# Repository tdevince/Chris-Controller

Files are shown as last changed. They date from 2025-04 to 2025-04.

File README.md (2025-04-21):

# Chris-Controller

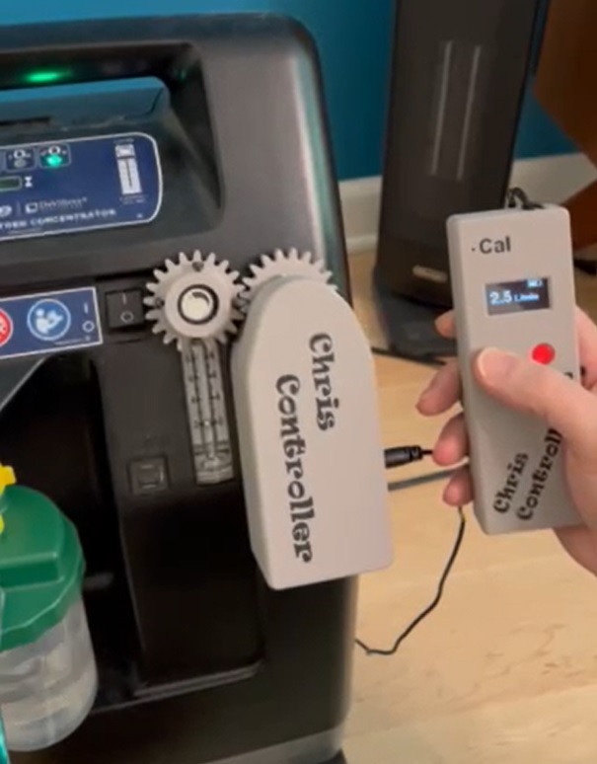
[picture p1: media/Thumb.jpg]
Watch the video
[](https://private-user-images.githubusercontent.com/97317875/435509045-00b4797d-aa02-43c4-9b9c-edfc26d2068e.mp4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)

This project is dedicated to my sister who is forced to live with a stationary oxygen concentrator 
in her house. The unit is extremely loud and not placed in a part of the house she wants to sleep 
or be in.  However, to change the oxygen flowrate, it is necessary for someone to do it at the machine.
For someone who is not mobile, this is a dificult task.  Further complicated by the fact that
in order to get up, she must first increase her oxygen flowrate.  Not possible without a caretaker
to go to the unit and manually change it.  

While some oxygen concentrators are available with remote control flow systems, they are not
FDA approved (as of this writing), as such medical supply companies do not provide these
units.

Her options are to increase the flow at the concentrator and use a second flowmeter at her location
that moves with her.  This creates a few problems, first the backpressure for the remote flowmeter
does not allow humidification at the concentrator to work properly.  Thus she is left with dry oxygen
which results in discomfort and nose bleeds.  Second, the backpressure can cause the concetrator
to alarm repeately.  Finally, this requires more hoses at her end of the system, which tangle and 
get caught when she tries to go to her walker or wheel chair.

The following paper by Duke University (https://pmc.ncbi.nlm.nih.gov/articles/PMC10122499/) provides
the basis for which this project is undertaken.  The project recommends that the controller at the 
stationary concentrator communicate via Bluetooth to a iPhone.  This requires an app on the iPhone to
controll the unit at the concentrator.  Since I'm not that well versed in creating applications for
the Apple Store, I instead created a remote control unit (based upon the ESP32-S2 chip, using the
ESP-NOW protocol).  This system uses the 2.4GHz WiFi frequency, but does not require connection
to a local WiFi network.

Since the paper that describes the hardware is a non-commercial license (CC BY-NC 3.0), the hardware
portion of this project is non-commercial. However, the software code developed for this project
is licensed under GNU General Pulbic License

## Repository Files:

* Files necessary for 3D printing are in the folder "3D Print Files".
* The Fusion360 files used to create these files are in the folder titled "Fusion360"
* An instruction manual that describes the operation and use of the system is included as a *.pdf file in the "Instruciton Manual" folder.  
* The circuit was designed using KiCad 9.0.  The schematic as well as the PCB files are in the folder "KiCad 9.0 fiies".  This folder also has the gerber files, position files and BOM files necessary for ordering the PCB's from JLCPCB.com.
* Two other repositories are used for the code used to program the controller and the remote.  The links to these repositories are in the folders "Controller" and "Remote".

## Building the Controller:

To build the Chris Controller, you will need to make the controller as well as the remote control.  The Controller consists of 3 3D printed gears, a mounting plate for the stepper motor and potentiometer and a base and cover.  The Fusion 360 files used to create the files for printing are included.  The parts were output to *stl files that were imported into PrusaSlicer.  The 3D input and output files are included in the Controller Directory.  PETG was used to print all parts. The potentiometer mounting plate requires supports on the dished part that holds the potentiometer.  The Cover has supports on the portion of the opening that accepts the 12V plug.  No other parts required supports for printing.
The stepper motor used is the 28BYJ-48 stepper motor.  This motor is found in 12V and 5V versions.  This project used the 12V version.  The potentiometer uses is the Bourns 3590-2-103L 10k ohm multiturn potentiometer.  The output jack supplied with the stepper motor is the JST 5 pin XH series connector.  The mating male connector is used on the PCB.  The potentiometer is connected to the PCB using the 2 pin JST connectors (XH series as well).  
The controller for the stepper is the ULN2003A Darlington array DIP.  Rather than use an SMT part, the DIP package was used since this is a common failure point of stepper motor systems.  Thus, using a 16pin socket on the PCB, the ULN2003A is easily replaceable.
The PCB uses an ESP32-S2-Solo-2 module for a microcontroller.  This module has the WiFi antenna included.  The code for the controller and remote uses the ESP-NOW protocol for communication.  This eliminates the need for a WiFi connection but provides superior range over a Bluetooth connection.  

The schematic and gerber files to order the PCB are provided in the KiCad directory.  The BOM used to order the PCB’s do not include the ESP32 module or any through hole parts (sockets, etc.) since these are easily added.  The ESP32 module is relatively inexpensive, but when supplied as a separate module, and not part of development kit, it must first be programmed prior to soldering to the PCB.  There is no way to update the firmware of the ESP32 once installed, other than Over-The -Air updates.  Therefore, the first loading of the firmware requires a wired connection to a PC.  Using a development board with flexipins allows for easy programming of the ESP32 module before installing.  If such a board is not available (I made my own for such purposes), the schematic and PCB can be redesigned to use a ESP32-S2-DevkitC-1.  This will increase the footprint of the PCB, but can be made functional.
The power supply used is a standard 12VDC adapter.  The stepper and ULN2003A take 12V inputs, the ESP32 is supplied with 3.3V from a buck switching regulator.  A switching regulator was chosen for its efficiency.  If a linear regulator is used, accommodation for heat dissipation must be considered since dropping from 12V to 3.3V will involve significant heat on linear regulators.

## Building the Remote:

The remote 3d files print a total of 7 items.  These are:
	Remote Cover
	Remote Base
	Up Button
	Down Button
	Battery Box
	Battery Box Cover

The Remote Cover and the Battery Box print as two items each if you want to print text(on the cover) and battery icons (on the battery box).  The text and icons are two different parts in the Fusion360 files.

To print different colors on the same layer in Prusaslicer, first go to “General” settings and change the number of extruders to 2.  Then on the Custom Code, enter “M600” for tool change.  This will cause the printer to pause and prompt to load a new color.  This method works well when only one or two layers need a different color inserted (such as text or battery icons).  When using this method, it is best if the text/icon part is part #2.  This way the rest of the layer is printed first, and success rate is higher in getting the text to look good without lifting or other print errors.

The *.gcode files are set up to print the multicolor as described above.  The cover is designed to have a 1mm thick acrylic sheet as a display window to protect the OLED screen.  The window cover should be cut and fit to the space in the cover before gluing.  Use a 5 minute epoxy rather than a CynoAcrylic (CA, Superglue, etc.) type of glue.  The CA glues will tend to fog the acrylic sheet.

The battery box uses a total of 8 keystone style 5209 terminal clips.  The clips are inserted into the box, and the tabs then bent outward 90 degrees.  The tabs then may be soldered to provide the 4 cells in series (i.e. positive to negative with the first and last tabs being the +6V and -0V tabs).

The positive tab is then routed to the slide switch (the cover is designed to use the CW Industries model G-107-SI-0005 slide switch.  The output of the slide switch, with the negative terminal of the battery box are then connected to the PCB using a JST XH series two pin connector.

Once the battery box is soldered, it may then be glued into the cover.  There are indexing tabs designed into the battery cover for the battery box.  

The two buttons (Up and Down) are also printed in PETG, I used red to offset it from the urban grey I used for the remainder of the remote.  These buttons merely fit inside the cover and are held into position by the PCB and push buttons.  The push buttons used are similar to https://www.amazon.com/Tactile-Switch-Momentary-Arduino-6x6x5mm/dp/B06XRH6GNX

Only two buttons are exposed by to the push buttons that are printed (the up and down buttons).  The calibration button is accessible using a paper clip through the small hole in the upper left of the remote cover.  The fourth button of the PCB is for OTA updates and is not accessible with the cover in place.

The remote uses a 1.3” OLED monochrome I2C display.  Note the order of the 4 contacts on the PCB to ensure that the one you are using will work, if not a redesign of the PCB may be necessary so that SDL, SCL, VCC and GND align.  The OLED uses the SH1106 chip, thus the library for the remote codes is built around this display.

Similar to the controller, the remote uses an ESP32-S2-Solo-2 bare module (https://www.digikey.com/en/products/detail/espressif-systems/ESP32-S2-SOLO-2-N4/16591892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) .  

The module will need to be programmed before soldering to the PCB, so that OTA updates are possible.  The advantage of using the bare module rather than development board is that it drastically reduces the footprint on the PCB (thus a smaller remote) as well as reducing the vampire load when the module is put to sleep.  Most development boards use a linear voltage regulator, which will consume much more battery power than the switching regulator used in this design.

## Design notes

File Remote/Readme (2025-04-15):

The code for the Chris Controller Remote is in the following repository:

https://github.com/tdevince/ESP32_Chris_Remote.git

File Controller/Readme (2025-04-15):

The code for the controller is located in the
following repository

https://github.com/tdevince/ESP32_Chris_Controller.git

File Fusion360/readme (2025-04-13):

This folder includes the Fusion360 files that wwere used to create the 3D printed
files for the controller and remote enclosure as well as gears.

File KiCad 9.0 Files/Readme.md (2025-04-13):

This folder contains the KiCad files for the schematic and PCB layout
in the formate required by JLCPCB.com.  Also included is the BOM and
position file that JLCPCB requires for assembly.  The BOM and postion
file do not include information the push buttons, connectors or
ESP32-S2-Solo-2 module since these are manually soldered after
receipt of the manufactured PCB's.

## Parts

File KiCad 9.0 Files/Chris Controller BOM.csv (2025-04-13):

Comment | Designator | Footprint | LCSC Part Number
4.7uF | C1 | Capacitor_SMD:C_1206_3216Metric | C29823
100nF | C2 | Capacitor_SMD:C_0402_1005Metric | C307331
1uF | C3 | Capacitor_SMD:C_1206_3216Metric | C1848
22uF | C4,C5,C6 | Capacitor_SMD:C_0805_2012Metric | C45783
1uF/25V(10%) | C7 | Capacitor_SMD:C_0402_1005Metric | C52923
10uF/25V(20%) | C8 | Capacitor_SMD:C_0603_1608Metric | C96446
0.1uF/50V(20%) | C9 | Capacitor_SMD:C_0603_1608Metric | C14663
24k | R1 | Resistor_SMD:R_0603_1608Metric | C23352
10k | R2 | Resistor_SMD:R_0603_1608Metric | C25804
10K | R3 | Resistor_SMD:R_0402_1005Metric | C25744
22k | R4 | Resistor_SMD:R_0603_1608Metric | C31850
TPSM33625 | U1 | Library:QFN-FCMOD | C7073593

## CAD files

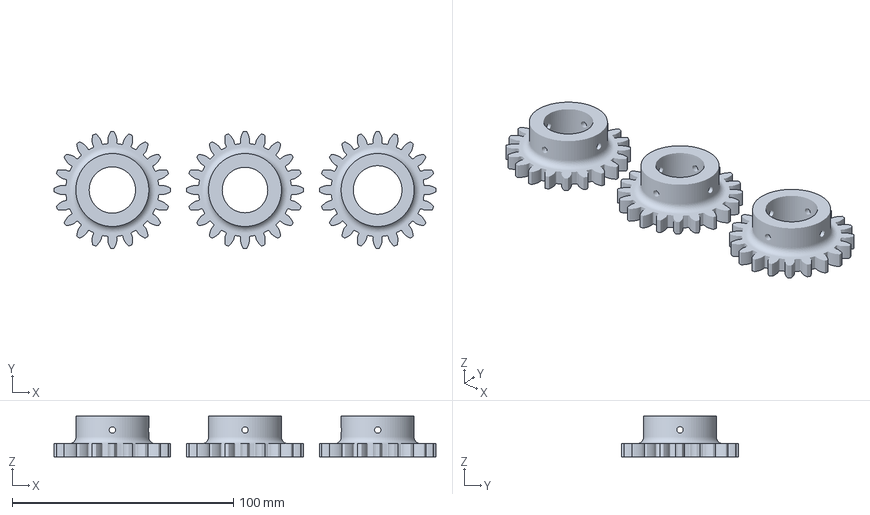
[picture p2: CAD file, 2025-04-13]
3D Print Files/Controller/Knob Gear Set.3mf
172.8 x 52.8 x 18.5 mm

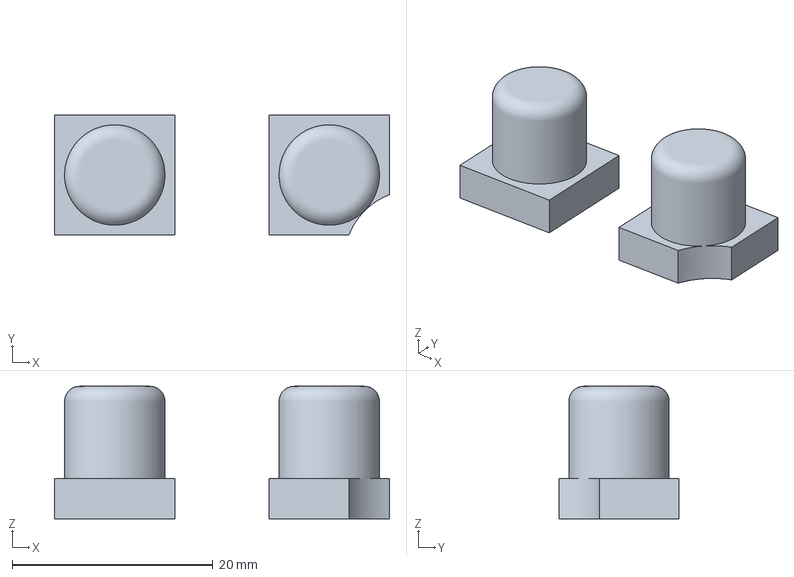
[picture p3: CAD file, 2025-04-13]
3D Print Files/Remote/Buttons.3mf
33.4 x 12.0 x 13.2 mm

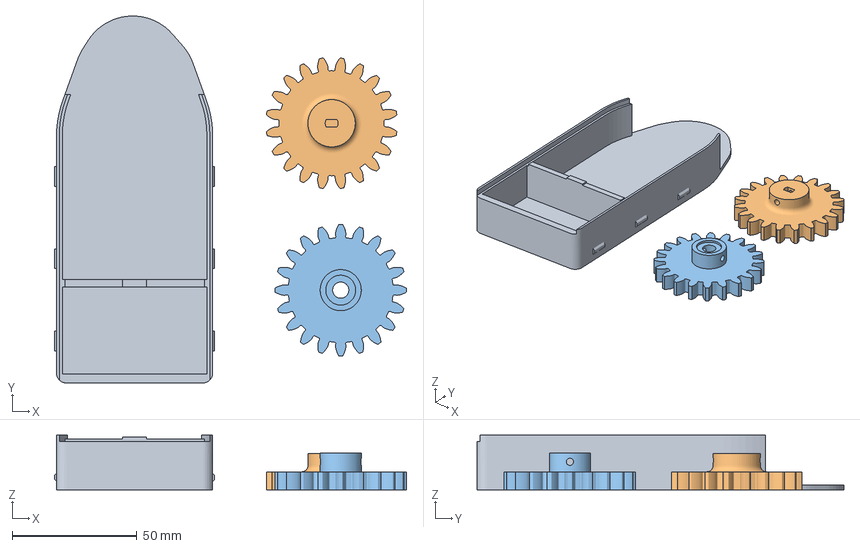
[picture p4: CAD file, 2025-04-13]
3D Print Files/Controller/Base and gears.3mf
141.3 x 147.3 x 22.0 mm
Base.stl
Drive Spur Gear (20 teeth).stl
Pot Spur Gear (20 teeth).stl

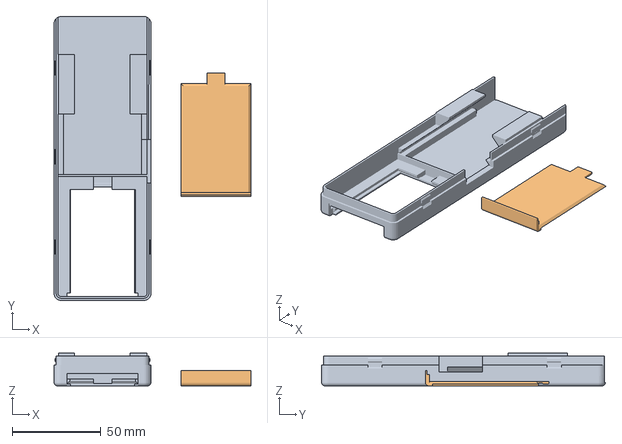
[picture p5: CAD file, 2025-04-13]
3D Print Files/Remote/Base and Cover.3mf
111.2 x 160.4 x 18.5 mm
Base.stl
Batt Cover.stl

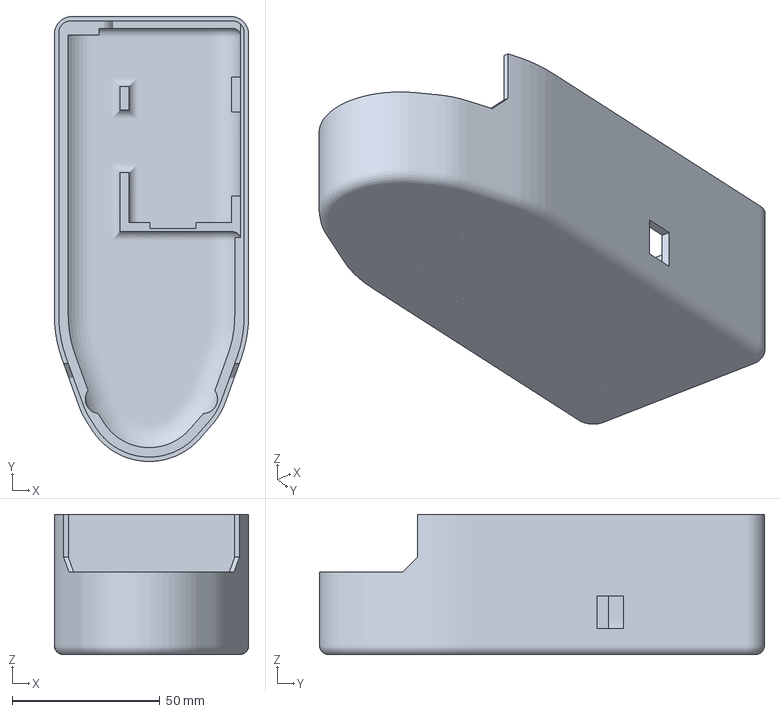
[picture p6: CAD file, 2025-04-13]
3D Print Files/Controller/Cover.3mf
65.8 x 150.7 x 47.5 mm

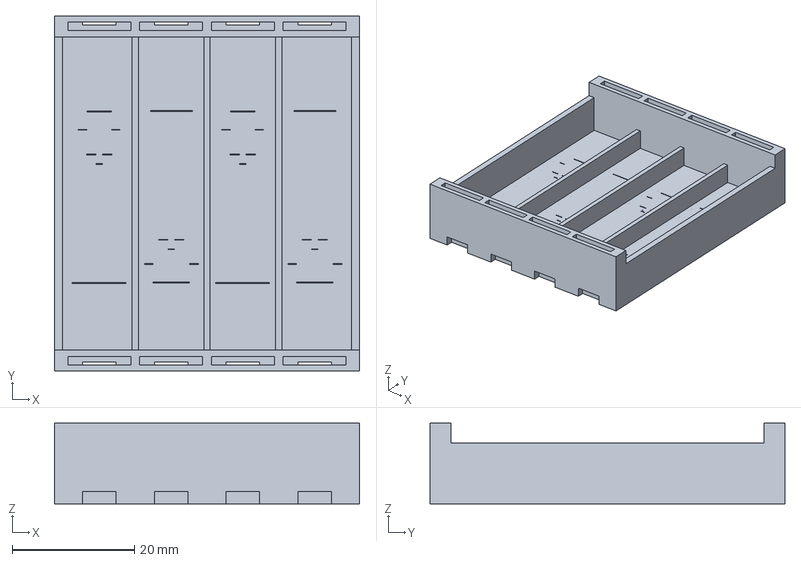
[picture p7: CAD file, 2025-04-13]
3D Print Files/Remote/Batt Holder.3mf
50.0 x 58.2 x 13.2 mm

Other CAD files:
Fusion360/Remote v21.f3d

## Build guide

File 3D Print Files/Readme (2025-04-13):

The files here were printed on a Prusa3d MK4S printer.
PETG was used for all parts, Urban Greay prusament was 
used for the enclosures, black for text and Red for 
the buttons.  
Prusaslicer was used to create the binary gcode files.

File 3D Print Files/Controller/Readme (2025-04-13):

The Fusion360 model was used to create the *.stl
files that were then imported into PrusaSlicer

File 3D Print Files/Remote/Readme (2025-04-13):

The fusion360 model was used to create *.stl files
that were used to make the .3mf files for Prusaslicer

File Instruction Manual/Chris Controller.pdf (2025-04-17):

# Chris Controller

# Static Oxygen Concentrator Remote Control System

### Table of Contents

Safety Information:
The following information is important for the safe operation of the Chris Controller system. Read through the entire manual and familiarize yourself with the system before using the system. Failure to do so may result in injury or death. Pretty dramatic, huh! Now you have to ask yourself if you really want to use something that could result in injury or death.

Rotating Machinery: This system has exposed rotating gears. Do not wear dangling or loose fitting clothing or jewelry that may get caught in the rotating gears. The Controller uses the powerful 28BYJ-48 motor in the 12V version. While it may not be enough to harm a finger, it can do serious damage to the stoutest of commercial plastic drinking straws.

Choking Hazard: There is nothing edible in this system. Every effort was made so that it doesn’t look like food. If you try to eat it, you will probably choke on it. If you’re that hungry, just get a candy bar instead.

Not a Toy: Apparently some people think it’s a good idea to give children plastic bags to play with. That is why so many manufacturers say not to play with plastic bags. To prevent you from giving children plastic bags as toys, this product is supplied without any plastic bags. Give your children a proper toy instead.

Prop. 65 Warning: Like everything else, this can cause cancer in the state of California. So do the safe thing and keep you and your loved ones out of the state of California!

Psychological Hazard: Unfortunately oxygen concentrator flow rates are typically metric (L/min). While no one knows what an “L/min” is (everyone knows what a “cubic foot per hour” is, though) this system uses metric so that it remains consistent with the oxygen concentrator system of units. For that reason, all parts of the design of this system is in metric units. For example, the set screws used are metric and use metric hex wrenches (2.5mm). While the metric system can cause psychological harm, it was determined the mixing of units would be more damaging. Thus only metric is used in the Chris Controller system.

Introduction
Stationary oxygen concentrators are typically loud and cannot be placed in rooms where one is trying to sleep or reside. Long lengths of tubing are used to connect the user to the concentrator, so the user is not in the same room with the concentrator. This presents a problem when the user needs to change the oxygen flowrate. For example, if the resting oxygen flow rate is lower than the flow need to get up and walk, then the user must increase the oxygen flow before getting up. But if the concentrator is not in the same room, another person must be available to change the flowrate.

The technical paper from Duke University titled “Design and Development of a Novel System for Remote Control of Stationary Oxygen Concentrator Flow Rate” by authors Nikhil Gadiraju, Nikhil Peterson, Jessica Shah, Annabelle Chu, Michael A Larbie II, Amy Bu, Ann Saterbak was the basis for this project (See Attachment 1).

The Chris Controller system was designed to work on the DeVilbiss Drive 10 Liter Oxygen Concentrator. This concentrator uses a manual flow meter to adjust the delivered Oxygen flow. This is similar to many concentrator designs, as such; the Chris Controller is designed to be easily adaptable to other concentrator designs.

The Controller works by grabbing the knob that adjusts the oxygen flow and turning the knob by use of a stepper motor. The Controller system is delivered with a set of three gears to grab the knob. Each of these gears is labeled 1 through 3; choose the one that best fits your knob. Gear 1 has a straight opening and provides the greatest clearance for the knob. Gears 2 and 3 have a slight taper to the opening that fits the knob, with Gear 2 being a little tighter than Gear 3.

The remote control has a set of Up/Down buttons. When Up is pressed the gear on the knob will rotate counterclockwise. On the DeVilbiss concentrator, this increases flow. If your concentrator design is opposite, then the Up/Down buttons will work opposite (Up will decrease flow, Down will increase flow).

The intent of the system is that no modifications to the concentrator are necessary. Since many people do not own the concentrator, but are instead supplied via a medical supply company, modification of the concentrator was not an option. The knob gear grabs the flow knob with a set of 4 set screws. The Controller itself is attached to the concentrator with the use of double sided tape (e.g., 3M double sided tape). No drilling or screwing into the concentrator is required for the Controller system to function.

The system includes:
- Chris Controller
- Chris Controller Remote
- Set of 3 knob gears (only one required for operation)
- AC Adapter (12VDC Output)
- Four AAA alkaline batteries

The Controller is powered by the AC adapter. The Remote uses four AAA batteries. The life of the batteries is dependent upon usage of the system.

The brains of the system are the Espressif ESP32-S2-Solo-2 microcontroller modules. These modules use an 802.11 Wi-Fi standard for communication. But instead of requiring a connection to a Wi-Fi network, the Remote and Controller communicate using Espressif’s ESP-NOW wireless protocol. This provides quicker response time than using a Wi-Fi network, while providing the superior range of Wi-Fi over Bluetooth. The Remote and Controller communicate on the 2.4GHz frequency (same as Wi-Fi networks). They use a “peer to peer” network based upon the MAC address of each ESP32 module. This information has been coded into the firmware; no pairing of devices is required by the user.

Documentation for this project, including source code and 3D models can be found at:

https://github.com/tdevince/Chris-Controller

Chris Controller:
The Controller consists of a stepper motor, a multi-turn potentiometer, a set of gears (flow meter knob gear, drive gear and pot gear). The stepper motor is able to precisely move the flow meter knob (via the gearing) in either the up or down direction (counterclockwise or clockwise). The stepper motor does not have a stop and can continue to travel in one direction infinitely.
The stepper motor is not capable of knowing where in the flow range it currently resides. It only knows turn clockwise or counterclockwise by so many steps. The stepper motor used is the 28BYJ-48 motor. This motor is most commonly available in the 5V version; this Controller uses the 12V version. The motor itself has 32 steps per revolution, but is internally geared so that it takes a total of 2048 steps to complete one rotation of the output shaft.

The potentiometer is the memory of the system. A potentiometer is a variable resistor. By turning the potentiometer we can increase or decrease resistance. The potentiometer used in the Chris Controller is a 10 turn 10kOhm resistor (Bourns model 3590S-2-103L). This means at one end of travel the resistance is 0 ohms. At the other end of travel (10 turns later), the resistance is 10,000 ohms. One complete turn of the potentiometer is equal to 1000 Ohms. By including the potentiometer in the gear train, we turn the potentiometer the same time and the same amount as we turn the flow knob when the stepper motor is engaged. All gears have the same number of teeth, so every gear turns in synchronization with each other.

After calibrating the system, the resistance of the potentiometer is directly proportional to flow rate. If power is lost, the potentiometer will retain the flow setting of the concentrator.

The system will not allow the stepper motor to hit the hard stops of the potentiometer. To help keep the full range of the full knob within the operating range of the potentiometer, it is recommended that the lowest flow rate (2.0L/min) be set with the potentiometer approximately 1.5-2 turns up from the low range stop.

Caution: Do not manually turn the flow knob, or gears while the drive gear is on the stepper motor. This may damage the internal gearing of the stepper motor.

To set the starting location of the potentiometer, remove the driver gear from the stepper motor. The gears or a snug fit on both the potentiometer and stepper motor. The gears are held to the shaft of these components with a pair of set screws. The set screws use a 2.5mm hex wrench (Allen wrench). With the drive gear removed, rotate the potentiometer gear all the way clockwise (as observed from the top of the Controller) until the stop is hit. Then rotate the gear 1.5-2.0 turns clockwise. Now reinstall the drive gear. When placing Controller on the concentrator, set the flow rate to the lowest setting (2.0 L/min). This will prevent the lowest setting of the Controller from hitting the hard stop of the potentiometer. This will provide approximately 8.5 turns of operation of the system. The concentrator flow meter will typically go from 2.0 L/min to 10.0 L/min in less than 5 turns.

The Controller is powered from the provided 12V AC adapter. This AC adapter provides an output of 12VDC with a maximum output current of 1.0Amps. This is well below the current draw of the Controller. Do not power the Controller with more than 12VDC since the stepper motor is only rated for a maximum of 12VDC.

The Controller has two modes of operation:
- Normal Mode
- Over-The-Air (OTA) mode

Operations to control the flow rate of the concentrator using the stepper motor occurs under the Normal Mode. Firmware updates to the Controller are only possible in the OTA mode. Firmware updates require a connection to a Wi-Fi network. The Printed Circuit Board (PCB) of the Controller has a button that will toggle the mode of the Controller from Normal Mode to
OTA Mode. This button is only accessible by removing the top cover of the Controller to expose the PCB.

By pressing the OTA button on the PCB, the Controller will reboot in the firmware update mode. The Controller will store the SSID and Password to connect to the local network. If the Controller has not connected to this network previously, it will present a Wi-Fi Manager Webpage that may be used to store the network SSID and Password.

While connected to a network, firmware updates may be carried out from a PC connected to the same network. Once the update is completed, pressing the OTA button on the PCB again will return the Controller to Normal Mode.

See the section on firmware updates for details.

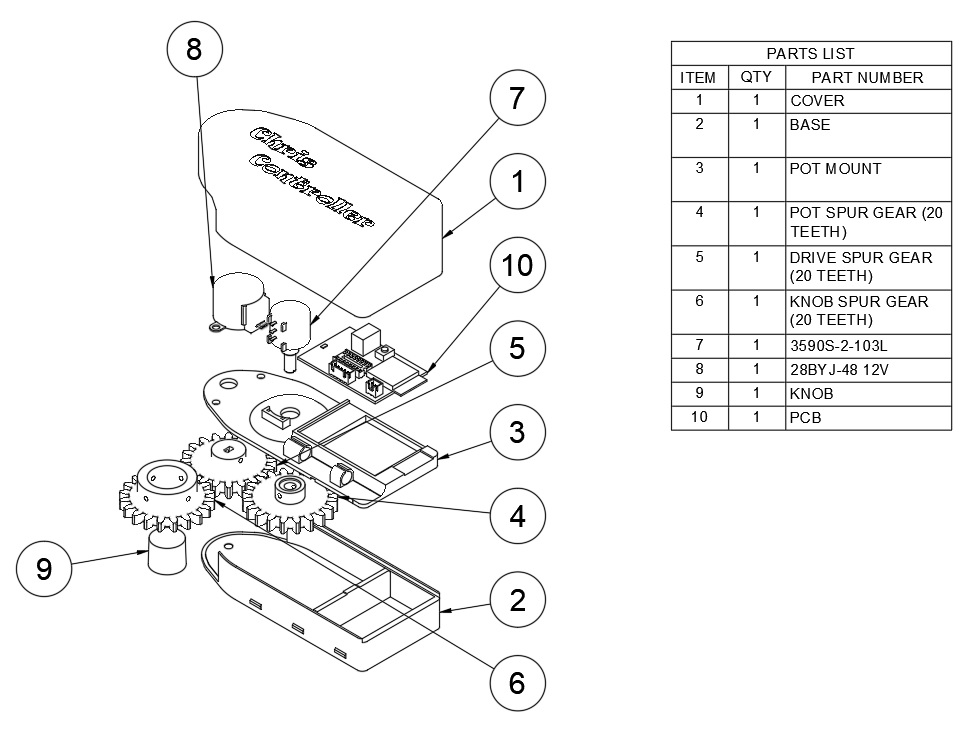
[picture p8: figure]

Page 7 of 18

Figure 1: Controller Exploded Diagram

Page 8 of 18

Remote:
The remote control is the user interface for the Chris Controller system. The Remote has two buttons, Up and Down, that allow the user to command the Controller to rotate the flow knob counterclockwise and clockwise, respectively. For concentrators where counterclockwise increases flow, the Up and Down button will increase and decrease flow, respectively.

The Remote also features a 128x64 OLED display screen. This screen will show the current oxygen flow rate for which the Controller is set. The upper right part of the display also provides an icon reflecting the remaining capacity of the 4 AAA alkaline batteries.

The upper left of the Remote has access to the Calibration feature of the Remote by inserting a paper clip (or similar object) into the hole marked “Cal”. This will press the “Cal” button on the PCB. Once the “Cal” button is pressed, instructions on how to calibrate the system is provided.

While the potentiometer of the Controller stores the current position of the concentrator flow knob, the Remote is the device that correlates the potentiometer resistance to an actual flow rate. The calibration information is stored in non-volatile memory; therefore the information is retained after the Remote has been powered down.

A slide switch on the side of the Remote turns the power on/off from the batteries to the PCB. This slide switch physically interrupts the battery to PCB connection. While powered up, to conserve batteries, the Remote display and Remote ESP32 module will go to sleep after 15 seconds of inactivity (while in the normal mode of operation). To wake the Remote, a single press of either the Up or Down button will wake the Remote. If the system is not going to be used for an extended period of time, the slide switch is the preferred method to turn the Remote off since this will conserver battery life.

The Remote during normal operation consumes approximately 60-70mA of current. When in sleep mode, this value drops to approximately 0.14mA. A typical AAA battery provides approximately 1000mA-hr of capacity. If the Remote were to be left in sleep mode, the batteries should last approximately 300 days. This value will vary by the frequency of use and the quality of batteries used. The slide switch eliminates all “vampire” loads, so that 0.0 mA are used from the batteries while powered off.

Similar to the Controller, the Remote has an OTA button on the PCB. This button is only accessible when the PCB is exposed.

The top of the Remote has a post and hole that is designed to have a lanyard attached. This feature will help avoid the dreaded “Where did I put that @*%&@#?ing Remote”crisis.

The Remote has 3 modes of operation:
- Normal Mode
- Calibration Mode
- OTA mode

Normal Mode:
Normal Mode is used for controlling the oxygen flow via the Controller. By holding the Up or Down button, the display will increase the flow demand in 0.5 L/min increments. 2.0L/min being the lowest and 10.0 L/min being the maximum flow settings possible. Once the desired flow rate is displayed on the Remote, release the buttons. When the buttons have been released for 1 second, the Remote will send the new flow demand to the Controller. The Remote will display the message “waiting…” while the Controller adjusts the flow rate. When the Controller reaches the desired flow rate, it will respond to the Remote with the current potentiometer setting. The Remote will convert this value and display it as the new oxygen flow rate.

After 15 seconds of inactivity, the Remote will go to sleep. Pressing either the Up or Down buttons will wake the Remote. Upon waking the Remote will inquire from the Controller its current position. When the Controller responds with the current potentiometer setting, the Remote will convert this value and display the corresponding oxygen flow rate.

Calibration Mode:
The Remote must be calibrated to be able to convert potentiometer values to an oxygen flow rate. Calibration is only required when initially setting up the Chris Controller. Once it has been set up, the calibration data is retained in non-volatile memory. The only time a Calibration would be required is if the flow knob is moved independent of the Controller (i.e. the flow knob on the concentrator manually moved with the Controller not installed). If the Controller is ever removed and reset on the concentrator, the calibration procedure should be repeated.

Caution: Do not manually turn the flow knob, or gears while the drive gear is on the stepper motor. This may damage the internal gearing of the stepper motor.

OTA Mode:
The OTA mode allows firmware updates of the ESP32 module of the Remote. While in Normal or Calibration Mode, the Remote is using the ESP-NOW protocol to communicate with the Controller. To enable firmware updates, the Remote must disconnect from the Controller and connect to the local Wi-Fi network.

Pressing the OTA button on the PCB will toggle the OTA Mode, and reboot the ESP32 module. Upon booting up, the ESP32 module will log on to the local Wi-Fi network using its stored SSID and Password for the Wi-Fi network. If the Remote has not connected to the Wi-Fi network previously, it will deploy its Wi-Fi Manager Webpage. This Webpage may then be used to log onto the network. Once logged on to the Wi-Fi network, the firmware on the ESP32 module may be performed with a PC connected to the same Wi-Fi network.

When logged onto the local network in OTA mode, the Remote display screen will show that the Remote is in OTA update mode and will also display its IP address. While in OTA mode, the Remote will not go to sleep.

After updating the firmware, another press of the OTA button will reboot the Remote in the Normal Mode. See the section on firmware updates for details

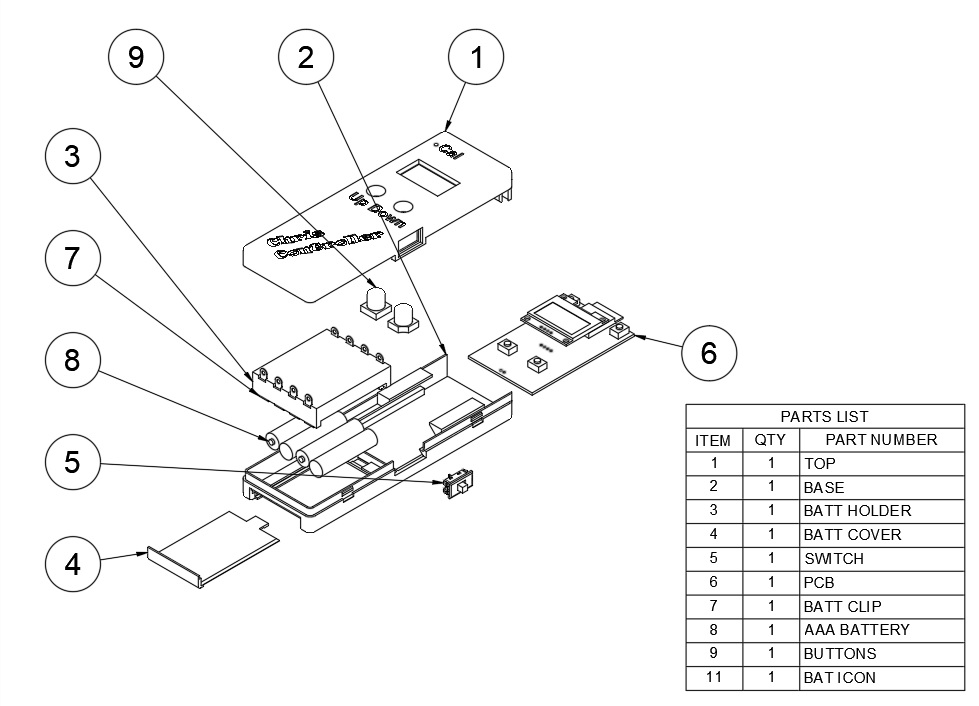
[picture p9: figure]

Page 11 of 18

Figure 2: Remote Exploded Diagram

Page 12 of 18

Installation and Setup:
The Chris Controller only requires 8 simple steps for installation. The required items for this installation that were not provided with the system are:
- 2.5mm hex wrench (Allen wrench)
- Double sided tape
Step 1:
Determine where on the concentrator the Controller should be located. On the DeVilbiss Drive 10 Liter Oxygen Concentrator, the Controller is designed to be affixed to the right of the flowmeter and flow knob. The Controller should not be installed such that the flowmeter is blocked. The drive and flow knob gears are designed to have a lateral separation of 48mm (1.9”). So the Controller should be placed such that the drive gear is offset this distance from the flowmeter.
Step 2:
Choose the appropriate flow knob gear to use. The system is supplied with three gears, each labeled 1, 2 and 3. Gear 1 has a straight wall opening to accommodate the knob, and will provide the greatest clearance. Gears 2 and 3 have tapered openings to accommodate the knob, with Gear 2 having tighter tolerances than Gear 3. The knob to choose will be the one that fits loosely around the knob but minimizes the clearance between the knob and gear.

Attach the knob by gradually tightening the 4 set screws. These screws should be used to align the gear so the knob is as close to the center of the opening as possible. By maintaining concentricity between the knob and gear, binding of gears can be minimized. Do not overtighten the set screws. It is only necessary to snug the screws so they adequately grab the knob and center the gear.

Step 3:
Dry fit the location of the Controller so that the drive gear meshes with the knob gear installed in
Step 2 above. The mesh should be slightly loose to prevent gear binding, but not so loose as to have significant backlash in the gearing. It may be necessary to reposition the knob gear up or down to ensure the drive gear and knob gear are at approximately the same height. Bear in mind when dry fitting that using a foam style double sided tape will slightly elevate the drive gear.
Step 4:
The Controller was delivered with the potentiometer set to 1.5 to 2.0 turns from the bottom stop. Therefore set the flow knob on the concentrator close to 2.0L/min to provide adequate margin when calibrating.
Step 5:
Place double sided tape on the bottom of the base of the Controller, and stick it to the concentrator such that the knob gear and drive gear mesh as described in Step 3.

Step 6:
Plug in the AC adapter and then plug it into the Controller to power the Controller.
Step 7:
Install 4 AAA batteries in the Remote, and then switch the power on the Remote. It will provide a Controller reading, this value is not accurate until the Remote has been calibrated.
Step 8:
Calibrate the Remote (See Calibration Section).

After completion of the calibration step, the Chris Controller system is ready for operation.

An optional lanyard may be attached to the post in the top of the Remote.

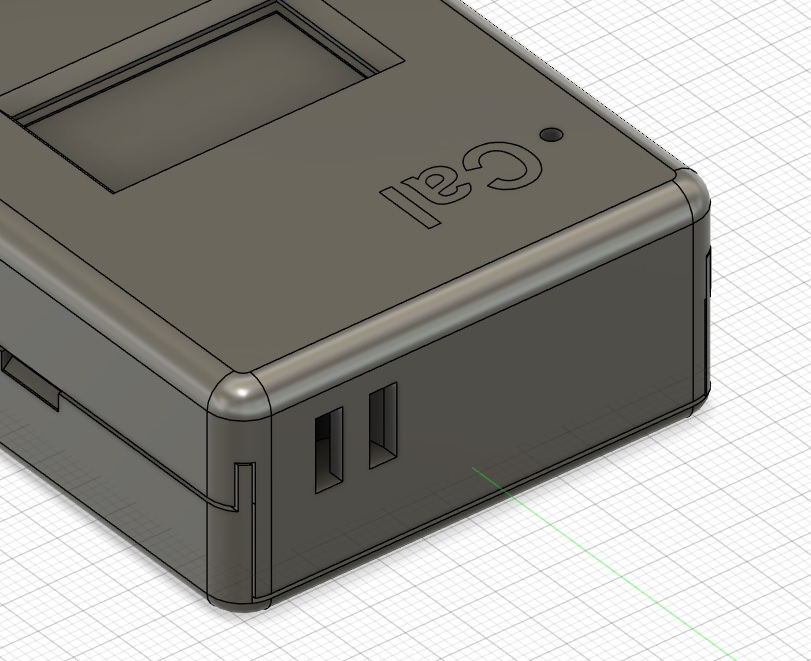
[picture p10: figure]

Figure 3: Remote Lanyard Post and Hole

Calibration:
Calibration of the system should be done anytime the knob and potentiometer gear are out of synch with each other. This will, at a minimum, be at the first installation of the system. Any other time when the knob is manually moved independent of the gear train, a calibration should be performed.

Caution: Do not manually turn the flow knob, or gears while the drive gear is on the stepper motor. This may damage the internal gearing of the stepper motor.

Calibration should be performed at the oxygen concentrator to allow visual readings of the flow rate during the process. The calibration process involves using the Remote to command the stepper motor to increase or decrease flow by pressing the Up or Down buttons. The Remote will identify the target flow rate for each step. When the target flowrate is displayed by the Remote, use the Up/Down buttons until the flowrate displayed on the oxygen concentrator matches the target value given by the Remote. When the target flowrate is achieved, pressing the Up and Down buttons simultaneously will enter this value into the Remote.

The stepper motor uses 2048 steps per revolution. Using the Remote Up or Down buttons will cause the stepper to in increments of 128 steps. This provides a resolution of 16 steps per revolution, or 22.5o
. This should provide adequate resolution for level of accuracy of the concentrator flowmeter.

The Remote will ask to repeat this process for a total of 9 data points from 2.0 to 10.0 L/min in 1.0L/min increments. After the last data point has been entered, the calibration data are saved to memory and the Remote will return to the Normal Mode.

To Calibrate the system, perform the following steps (note, the Remote will not go to sleep during calibration):

Step 1:
Ensure the Controller is powered up, turn on the Remote and wait for the display to show the current Controller position.
Step 2:
If the Remote is asleep, first wake the remote by pressing either the UP or Down button. Using a paper clip, or other similar object, insert it into the “Cal” hole located on the Remote. Press the button on the PCB with the paper clip. The Remote will now enter calibration mode and display a screen of instructions:

Cal. Mode: Use Up or
Dwn to turn controller
To desired flow. Press
Up & Down to ‘Enter’

Press the Up and Down button to progress to the next page.

Step 3:
After pressing the Up and Down buttons in Step 2, the user will be presented with the first target flow rate. Using the Up/Down buttons have the Controller increase/decrease flow on the concentrator until the flowmeter on the concentrator matches the target value displayed on the Remote. When the target value is achieved, simultaneously press the Up and Down buttons to enter the value. The Remote will then prompt the user for the next data point.
Step 4:
Repeat Step 3 until all data points from 2.0 through 10.0 L/min have been entered. The Remote only uses cardinal values for calibration. For values between the cardinal values (e.g., 2.5, 3.5… etc.), the Remote will linearly interpolate between the cardinal values stored.

After the target value for 10.0L/min has been reached and the Up and Down buttons pressed, the Remote will save the calibration data and return the Remote to Normal Mode.

If the Cal button is pressed again before the calibration procedure is completed, the Remote will return to Normal Mode without saving the calibration data. Similarly, if the Remote is switched off before the calibration procedure is completed; the Remote will return the Normal Mode when powered on again without saving the calibration data.

Firmware Updates:

The firmware on the Controller as well as the Remote can be updated “Over-the-Air” (OTA) using a local Wi-Fi network. During Normal and Calibration modes of operation, the Controller and Remote communicate without connecting to a Wi-Fi network. This simplifies normal operation and significantly increases system response time.

However to perform a firmware update, the unit being updated must disconnect from this “peer to peer” network and connect to a local Wi-Fi network. Both the Remote and the Controller have an OTA button the PCB that is not accessible when the top cover is installed. If the Remote is asleep, it will be necessary to wake the Remote by pressing the Up or Down button first.

Pressing the OTA button will reboot the Controller/Remote and look for the local Wi-Fi network for which it has stored SSID and Password information. If this is the first time connecting to the network, the Controller/Remote will start up its Wi-Fi manager Webpage. To access this Webpage, go to Settings>Wi-Fi on your iPhone (Android devices may be different). Then connect to the Wi-Fi manager shown in the list of Wi-Fi networks. For the Controller this will be labeled “Chris_Controller”, “Chris Remote” for the Remote.

The Wi-Fi Manager Webpage will then be displayed; the first option is to configure the Wi-Fi connection. Selecting this option will open a page requesting the network SSID and password. Scroll down through the list of displayed networks until you find the desired network. Selecting that network will pre-fill the SSID information. Next enter the password for that network and connect to the network.

If the SSID and Password are properly filled in, the Controller/Remote will reboot and connect to that network. If unsuccessful, the Controller/Remote will relaunch the Wi-Fi manager. It will be necessary to reconnect with your iPhone and re-enter SSID/Password. Typically connection errors occur when the Wi-Fi signal is weak, or a something was mistyped for SSID/Password.

Once connected to the Wi-Fi network, the Remote will display the IP address that it is using to connect to the network. The Controller has no such display, to find the IP address it will be necessary to find it from the network. Most Wi-Fi routers allow the user to see devices connected to the network. The device name for the Controller should show up in that list as “Chris_Controller”.

The firmware on both the Remote and Controller was programmed using Microsoft’s Visual Studio Code (VS Code) with the PlatformIO plug-in. To update the firmware using PlatformIO, use the espota protocol and specify the device IP address in the platformio.ini file. For example, for an IP address of 192.168.0.144, the following lines would be added to the platformio.ini file:

[env:esp32-s2-saola-1-ota]
upload_protocol = espota
upload_port = 192.168.0.140

The status of the upload will be displayed in the terminal window of VS Code. Once the update is shown to be completed and successful, pressing the OTA button on the Remote/Controller will reboot the device and start in Normal Mode with the updated firmware.

## Attachment 1:

### Design and Development of a Novel System for Remote Control of Stationary Oxygen Concentrator Flow Rate

by Nikhil Gadiraju, Nikhil Peterson, Jessica Shah, Annabelle Chu, Michael A Larbie II, Amy Bu, Ann Saterbak

O R I G I N A L R E S E A R C H

## Design and Development of a Novel System for Remote Control of Stationary Oxygen Concentrator Flow Rate

Nikhil Gadiraju *, Nikhil Peterson *, Jessica Shah *, Annabelle Chu, Michael A Larbie II, Amy Bu, Ann Saterbak

Pratt School of Engineering, Duke University, Durham, NC, USA

*These authors contributed equally to this work

Correspondence: Ann Saterbak, Department of Biomedical Engineering, Duke University, 101 Science Drive, Campus Box 90281, Durham, NC, 27708-0281, USA, Tel +1 919 660 5899, Fax +1 919 684 4488, Email ann.saterbak@duke.edu

Purpose: Long-term oxygen therapy involves utilizing stationary oxygen concentrators to allow patients with respiratory illnesses to attain sufficient blood oxygenation via supplemental oxygen. Disadvantages of these devices include their lack of remote adjustability and domiciliary accessibility. To adjust oxygen flow, patients typically walk across their homes – a physically taxing activity – to manually rotate the knob of the concentrator flowmeter. The purpose of this investigation was to develop a control system device that allows patients to remotely adjust the oxygen flow rates on their stationary oxygen concentrator.
Methods: The engineering design process was used to develop the novel FLO2 device. The two-part system is composed of 1) a smartphone application and 2) an adjustable concentrator attachment unit that mechanically interfaces with the stationary oxygen concentrator flowmeter.
Results: Product testing indicates that users successfully communicated to the concentrator attachment from a maximum distance of 41m in an open field, suggesting usability from anywhere inside a standard home. The calibration algorithm adjusted oxygen flow rates with an accuracy of ±0.019 LPM and a precision of ±0.042 LPM.
Conclusion: Initial design testing suggests the device as a reliable and accurate method of wirelessly adjusting oxygen flow on a stationary oxygen concentrator, but further testing should be performed on different stationary oxygen concentrator models. Keywords: oxygen therapy, respiratory disease, flow meter, wireless adjustment, medical device

Introduction

More than 1.5 million patients in the United States utilize supplemental oxygen to manage various respiratory conditions, including chronic obstructive pulmonary disease, lung cancer, cystic fibrosis, and amyotrophic lateral sclerosis.¹ Patients

with these respiratory diseases are unable to perform the normal physiological exchange of oxygen and carbon dioxide, resulting in oxygen deficiencies or hypoxia. Although the lung damage and resulting deficiencies associated with chronic obstructive pulmonary disease (COPD) are irreversible, home oxygen therapy can increase life expectancy and standard of living for patients who would otherwise struggle to complete daily tasks.² More specifically, COPD patients

experiencing chronic hypoxemia have demonstrated susceptibility to the health advantages and quality of life improvements afforded by long-term home oxygen therapy.³⁻⁵

Advancements in home oxygen delivery have enabled both stationary and portable oxygen concentrators to provide supplemental oxygen. Portable oxygen concentrators are utilized primarily in mobile, lightweight applications, and in the absence of a permanent power source.⁶ Most home oxygen therapy patients that are prescribed long-term oxygen therapy receive supplemental oxygen for over 15 hours a day through a stationary oxygen concentrator.³,7 Oxygen concentrators

function using a technique called pressure swing absorption in which nitrogen from atmospheric air is adsorbed onto

Medical Devices: Evidence and Research 2023:16 91–100 | 91

© 2023 Gadiraju et al. This work is published and licensed by Dove Medical Press Limited. The full terms of this license are available at https://www.dovepress.com/terms. php (https://www.dovepress.com/terms.php) and incorporate the Creative Commons Attribution – Non Commercial (unported, v3.0) License (http://creativecommons.org/licenses/by-nc/3.0/). By accessing the work you hereby accept the Terms. Non-commercial uses of the work are permitted without any further permission from Dove Medical Press Limited, provided the work is properly attributed. For permission for commercial use of this work, please see paragraphs 4.2 and 5 of our Terms (https://www.dovepress.com/terms.php).

Medical Devices: Evidence and Research | Dovepress (https://www.dovepress.com) open access to scientific and medical research

Open Access Full Text Article

Received: 20 February 2023 Accepted: 5 April 2023
Published: 18 April 2023

Medical Devices: Evidence and Research downloaded from https://www.dovepress.com/

For personal use only.

zeolite, a porous aluminosilicate material, producing an oxygen-rich gas. With this method, the oxygen concentration of 21% in atmospheric air can be increased to 90–95% in the gaseous product.⁸ Patients require different amounts of

supplemental oxygen when active, resting, and sleeping. Excessive oxygen can result in hyperoxia, while insufficient oxygen can result in hypoxia. Therefore, accurate adjustment of oxygen flow rate is necessary to avoid hypoxia and hyperoxia throughout daily changing activities.² Oxygen supplementation may need to be increased during periods of increased demand when patient activity increases, such as during exercise or when walking.⁹ Prior studies have shown

that patients with COPD and moderate hypoxia frequently have significant periods of poor oxygenation during daily activities and at night.¹⁰

As currently designed, patients or caregivers need to manually adjust the knob on the front of the device to increase or decrease oxygen flow rates. As a result, patients must walk across their homes – and sometimes up and down stairs – to turn the knob of the stationary oxygen concentrator flow meter to maintain adequate oxygenation. However, manual adjustment of oxygen flow is time-consuming and burdens patients, which often reduces therapy compliance.¹¹ Patients undergoing long-term oxygen therapy have previously expressed a need for remote control capabilities for stationary oxygen concentrators.¹² Furthermore, the

American Thoracic Society (ATS) has highlighted the development of remote-control flowrate adjustment technology as a key funding priority for overcoming barriers to supplemental oxygen delivery via stationary oxygen concentrators.¹

The limitations of current oxygen delivery methods led to the advances of new intelligent portable oxygen concentrators. For example, Sanchez-Morillo et al developed a portable oxygen concentrator that uses physiological sensors and predictors of oxygen desaturation to automatically adjust oxygen flow rates.¹³ However, there are few

developments in stationary concentrator technology that address the need for improved oxygen flowrate control and overall device accessibility.¹

To adapt oxygen therapy to the dynamic needs of patients and minimize oxygen desaturation episodes, we developed FLO2, a novel oxygen concentrator control system that is an external add-on for existing stationary concentrators. FLO2 allows patients to wirelessly control the flow rate of their oxygen concentrator using a mobile application. This innovation removes any physical activity associated with oxygen flow adjustment for both patients and family members, which will lower the risks of hypoxia and hyperoxia associated with home oxygen therapy.

Materials and Methods
Engineering Design Process
To design and build the FLO2 oxygen concentrator control system, the team used the engineering design process.¹⁴ The

engineering design process is an iterative workflow utilized to create novel products. As a part of this process, a problem was identified and researched, potential solutions were brainstormed and evaluated using a set of design criteria, a prototype solution was designed and produced, and this initial prototype was iteratively improved upon following testing. In narrowing down the initial set of potential solutions, the design criteria that were utilized during solution evaluation were: range of 30 meters, mobile application reliability of 97.5%, flow rate accuracy of 0.25%, and flow rate precision of 0.25% (Table 1). In summary, the team utilized the iterative engineering design process to produce FLO2, a device that met all established design criteria.

Table 1 Design Criteria with Definitions

Design Criteria | Definition
Bluetooth Range | Maximum distance the app remains connected to the concentrator attachment
Reliability | Bluetooth: Connects to attachment in under 10 seconds
| App Adjustment: User action consistently register on the app and are communicated to attachment
Flow Rate Accuracy | Closeness of the flow rate observed on the concentrator compared to the expected target flow rate
Flow Rate Precision | Closeness of the flow rates observed on the concentrator for each target flow rate

https://doi.org/10.2147/MDER.S407233
DovePress (https://www.dovepress.com)

### 92 Medical Devices: Evidence and Research 2023:16

Gadiraju et al | Dovepress (https://www.dovepress.com)

Powered by TCPDF (www.tcpdf.org) Powered by TCPDF (www.tcpdf.org)

Initially, a preliminary proof of concept was designed for both the communication and attachment modules. The initial communication module was composed of a simple Arduino-based Bluetooth transceiver that allowed users to utilize push buttons to elicit a verifiable response on another Arduino board; this proved user interface and wireless communication capabilities. The attachment proof of concept was a simple elastic clamping mechanism that modeled the module mounting contraption; all attachment proof of concepts were initially designed around the in-house oxygen concentrator, the Invacare Mobilaire V. Given these proof of concepts, iterative prototyping, involving rapid 3D-printing and design review cycles, was utilized to create an initial product prototype. This allowed for prototype iterations to be rapidly tested and refined until a final, viable prototype was created. This iterative prototyping process was repeated multiple times, with in-depth design reviews being conducted between processes. This led the product to transition from an attachment module designed purely for our in-house oxygen concentrator and a physical remote, to an adaptable attachment module and a mobile application.
For more informed refinements of the initial prototype, informal feedback was sought from community members with chronic lung diseases using home oxygen therapy (see Appendix (https://www.dovepress.com/get_supplementary_file.php?f=407233.docx) for survey). From a total of 12 survey responses, 91% of responders were prescribed multiple oxygen flow rates each day depending on their level of exertion. Within this group, two members stated that they were prescribed certain flow rates for different levels of exertion but never changed their flow rate due to the difficulty in adjusting it. The survey received mixed feedback on the preference for a slider or button form of flow rate adjustment, so both methods were included in the development of the mobile application. Responders pointed to the ability to adjust to half increments using a slider and the ease of use of pressing a button when explaining their preferences. Finally, the community members expressed a high degree of interest in the continued development of this product.
The final device solution, named FLO2, consists of two parts: 1) an adjustable oxygen concentrator attachment that clamps onto the flow meter of various oxygen concentrator models and 2) a mobile application that allows patients to wirelessly adjust their flow rate (Figure 1). The oxygen concentrator attachment is an external add-on that modifies the flow rate without interfering with the internal workings of the existing oxygen concentrator. The innovation allows patients to use an app on their smart device to change their flow rate from anywhere in their homes. After the FLO2 smartphone application receives user input, it wirelessly communicates with the oxygen concentrator attachment module via Bluetooth. This input prompts the attachment module to utilize a motor and gear system to mechanically rotate the knob on the flow meter of the oxygen concentrator accordingly. Subsequently, the attachment electronically updates the app with the new flow rate value via Bluetooth, which is then displayed to the user.

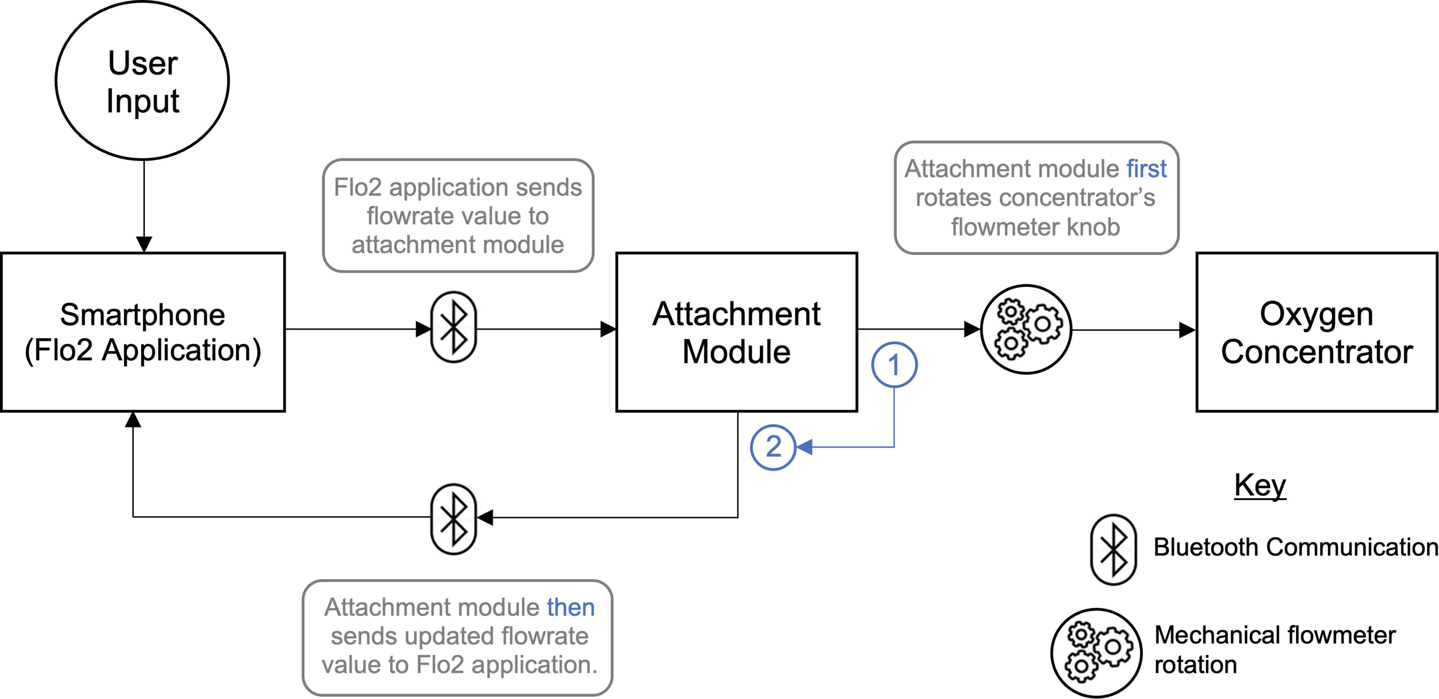
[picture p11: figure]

Figure 1 Block diagram overview of FLO2 System. User input is sent to FLO2 application, which then prompts attachment to module to first (1) rotate flow meter knob and then (2) send updated flow rate value back to application.

Medical Devices: Evidence and Research 2023:16 | https://doi.org/10.2147/MDER.S407233 DovePress (https://www.dovepress.com)
93
Dovepress (https://www.dovepress.com) | Gadiraju et al

Powered by TCPDF (www.tcpdf.org) Powered by TCPDF (www.tcpdf.org)

Attachment Module Housing

The attachment module was designed using Computer Aided Design (CAD) software and 3D-printed using polylactic acid (PLA). The attachment is set atop the oxygen concentrator flowmeter and works by using an adjustable horizontal clamping mechanism that laterally surrounds the flow meter (Figure 2). The right horizontal clamp was designed such that the user can read the oxygen flow rate ball position through the horizontal slot cutout in the case of product failure. Additionally, the vertical slider (Figure 2) can be appropriately adjusted to interface with the flow meter gear to allow for flow rate adjustment. The flow meter gear (Figure 3) attaches to the knob of the flowmeter using four adjustable set screws. This horizontal and vertical clamping mechanism was intentionally designed to allow for oxygen concentrator

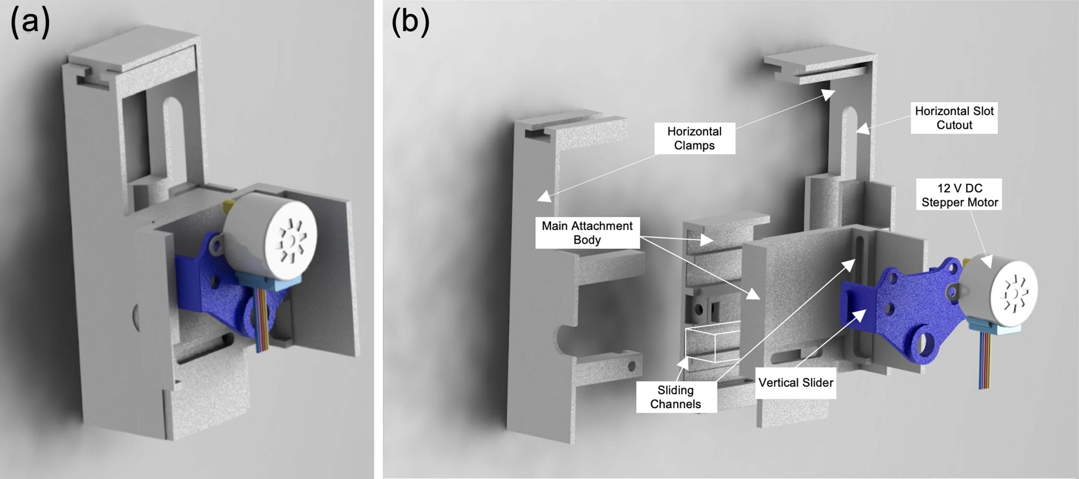
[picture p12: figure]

Figure 2 (a) CAD model of attachment module; (b) Exploded view of attachment module CAD model. The horizontal clamps and vertical slider function by moving through the appropriate sliding channels; they are held in place by tightening their respective set screws (not shown).

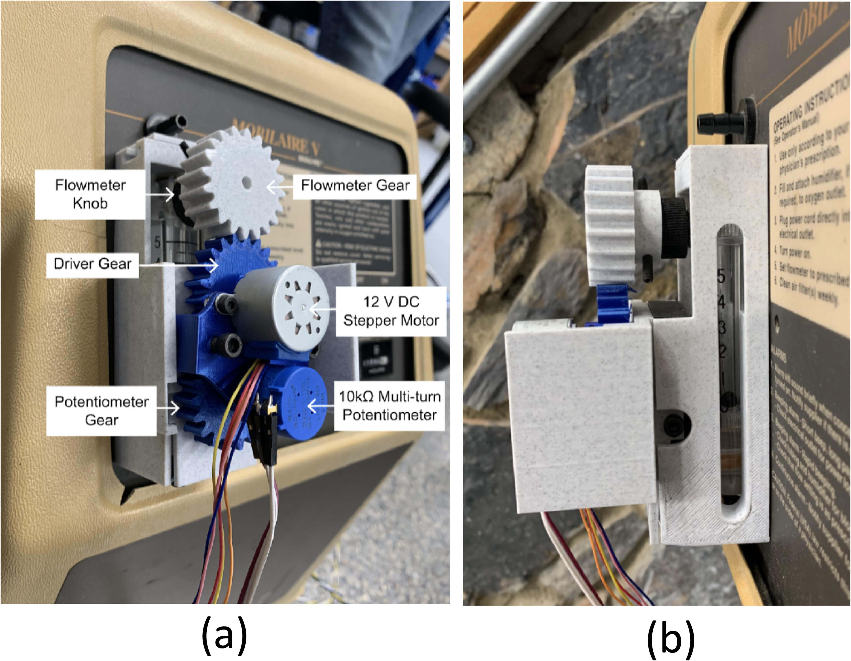
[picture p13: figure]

Figure 3 (a) Concentrator attachment module and gear system clamped to flow meter. (b) Concentrator attachment side view with an insert designed for users to read the oxygen flow rate ball position.

https://doi.org/10.2147/MDER.S407233
DovePress (https://www.dovepress.com)

### 94 Medical Devices: Evidence and Research 2023:16

Gadiraju et al | Dovepress (https://www.dovepress.com)

Powered by TCPDF (www.tcpdf.org) Powered by TCPDF (www.tcpdf.org)

adaptability. Rather than utilizing a static flowmeter slot for mounting, this designed clamp can adjust to various flowmeter and concentrator geometries, which allows this device to be compatible with many oxygen concentrator models.

Motor and Potentiometer

The stepper motor was placed to rotate the motor driver gear, which was connected to a gear attached to the flow meter knob and a gear attached to the potentiometer (Figure 3). Electronically, a circuit was designed using a Bluno Beetle BLE microcontroller (DFR0339; DFRobot), a 10kΩ 2W wire-wound linear multi-turn potentiometer (3590S-1-103L, Bourns Inc.), and a 12V 4 phase geared stepper motor (28BYJ-48; CenryKay). The microcontroller was powered using a 9V 2A AC/DC power supply (B087ZWS7CG; GuanTing), which was compatible with standard 110 V wall outlets; its power line runs alongside the oxygen concentrator’s power line (Figure 4).
The microcontroller was programmed using Arduino to control the rotational direction and position of the stepper motor based on the potentiometer input. The potentiometer was used to track the position of the flow meter, even when the concentrator attachment or the oxygen concentrator is not on. This was implemented as a safety mechanism for the FLO2 control system to track when the user manually turns the flow meter without the app or if the concentrator attachment accidentally powers off.
When the motor drive gear rotates, it adjusts the flow rate by rotating the flow meter knob via the flow meter gear and sends the current flow rate to the app by rotating the potentiometer via the potentiometer gear. During the calibration process, the potentiometer values that are associated with 0, 1, 2, 3, 4, and 5 LPM are recorded by the microcontroller and sent to the app. The potentiometer values associated with each 0.5 LPM increment are then interpolated. When a target flow rate is selected on the app, the app sends the previously stored potentiometer value to the microcontroller in

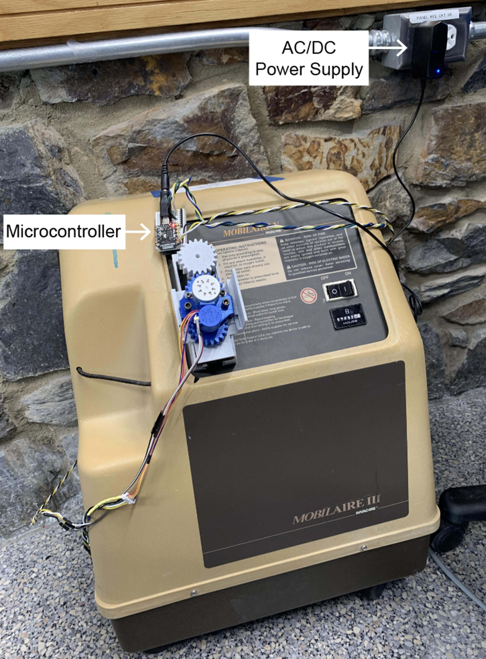
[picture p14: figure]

Figure 4 Full concentrator attachment view with electronics plugged into the 110V wall outlet.

Medical Devices: Evidence and Research 2023:16 | https://doi.org/10.2147/MDER.S407233 DovePress (https://www.dovepress.com)
95
Dovepress (https://www.dovepress.com) | Gadiraju et al

Powered by TCPDF (www.tcpdf.org) Powered by TCPDF (www.tcpdf.org)

the concentrator attachment. The microcontroller then signals the 12V DC stepper motor to rotate the flowmeter knob until the potentiometer value matches the target value.

Mobile Application

Mobile applications were developed for iOS and Android devices using Swift and Java, respectively, to allow users to control the oxygen flow using their smartphone (Figure 5). The app communicates with the Bluno Beetle microcontroller using Bluetooth 4.0 (BLE).
The app first requires the user to connect to the oxygen concentrator attachment via Bluetooth 4.0 (BLE) (Figure 6,
Step 1 and 2). To initially calibrate their device, the user manually turns the flow meter knob to each one integer increment (eg 0, 1, 2, 3, 4, and 5 LPM) and presses a button on the app to confirm the flow rate (Figure 6, Step 3 and 4). The potentiometer values at each of these flow rates are stored in the app. The potentiometer values associated with each 0.5 LPM increment are then interpolated. After the one-time calibration is finished, users can use the slider bar or one of the four editable button presets (Figure 6, Step 5 and 6) to choose their desired oxygen flow rate (Figure 5). The editable button presets were included to allow for easy adjustment to commonly used flow rates such as those prescribed by a physician for the varying activity levels of sleep, rest, and high activity. Each time the desired flow rate is selected, the phone updates the user with the current flow rate and sends the corresponding potentiometer value to the Bluno Beetle BLE microcontroller in the concentrator attachment. The microcontroller then signals the 12V DC stepper motor to rotate the flowmeter knob until the multi-turn potentiometer value matches the value corresponding to the desired flow rate.

Results

To evaluate the design, the team tested the prototype according to the following design criteria: Bluetooth range, reliability, flow rate accuracy, and precision (Table 2). Testing was performed on the Invacare Mobilaire V stationary oxygen concentrator.
The Bluetooth range was defined as the maximum distance the app remained connected to the concentrator attachment. A range of at least 30 meters was desirable to ensure that the device would stay connected within the confines of even a relatively large home. The range was tested by identifying how far the app could be from the

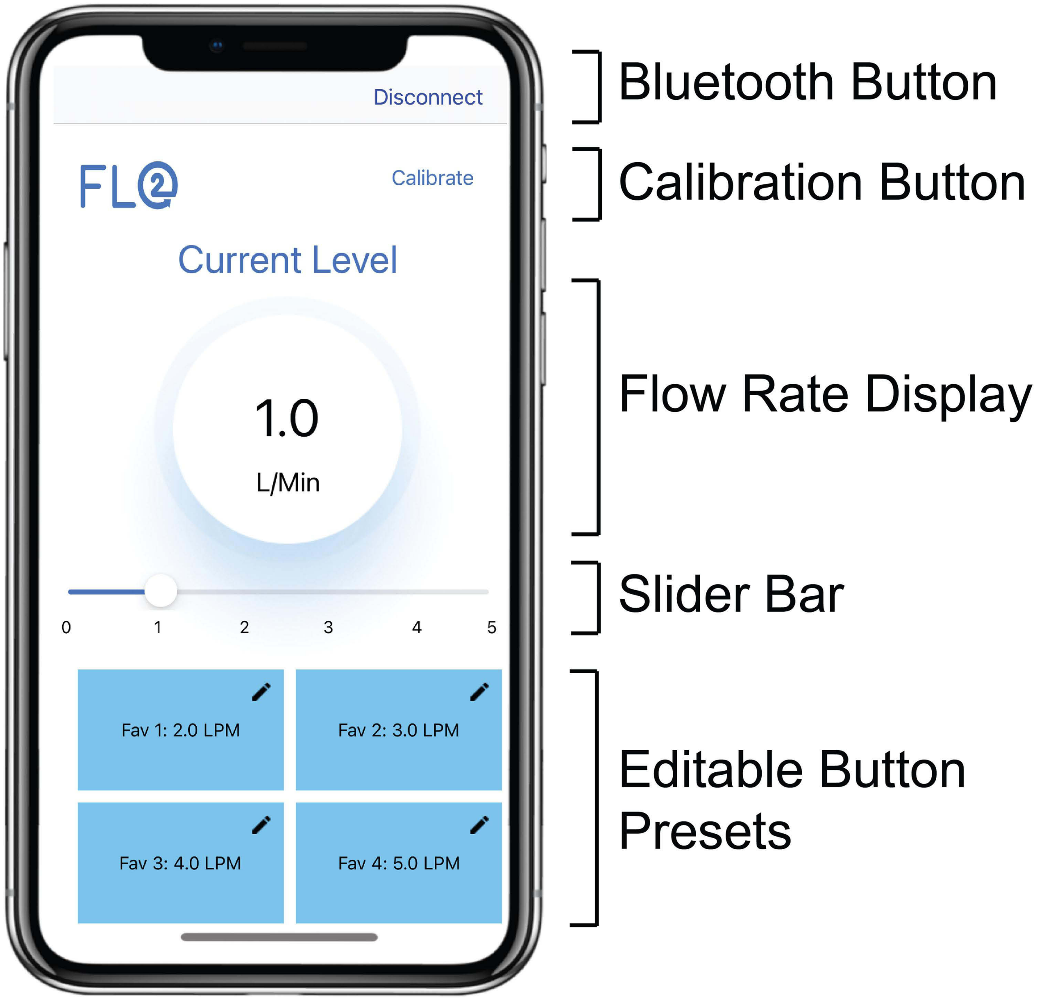
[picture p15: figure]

Figure 5 FLO2 application home page with current flow rate display, Bluetooth button, and calibration button. Users can adjust the flow rate by 1) sliding the slider bar to any 0.5 increment value between 0 and 5 LPM or 2) selecting one of the four editable button presets.

https://doi.org/10.2147/MDER.S407233
DovePress (https://www.dovepress.com)

### 96 Medical Devices: Evidence and Research 2023:16

Gadiraju et al | Dovepress (https://www.dovepress.com)

Powered by TCPDF (www.tcpdf.org) Powered by TCPDF (www.tcpdf.org)

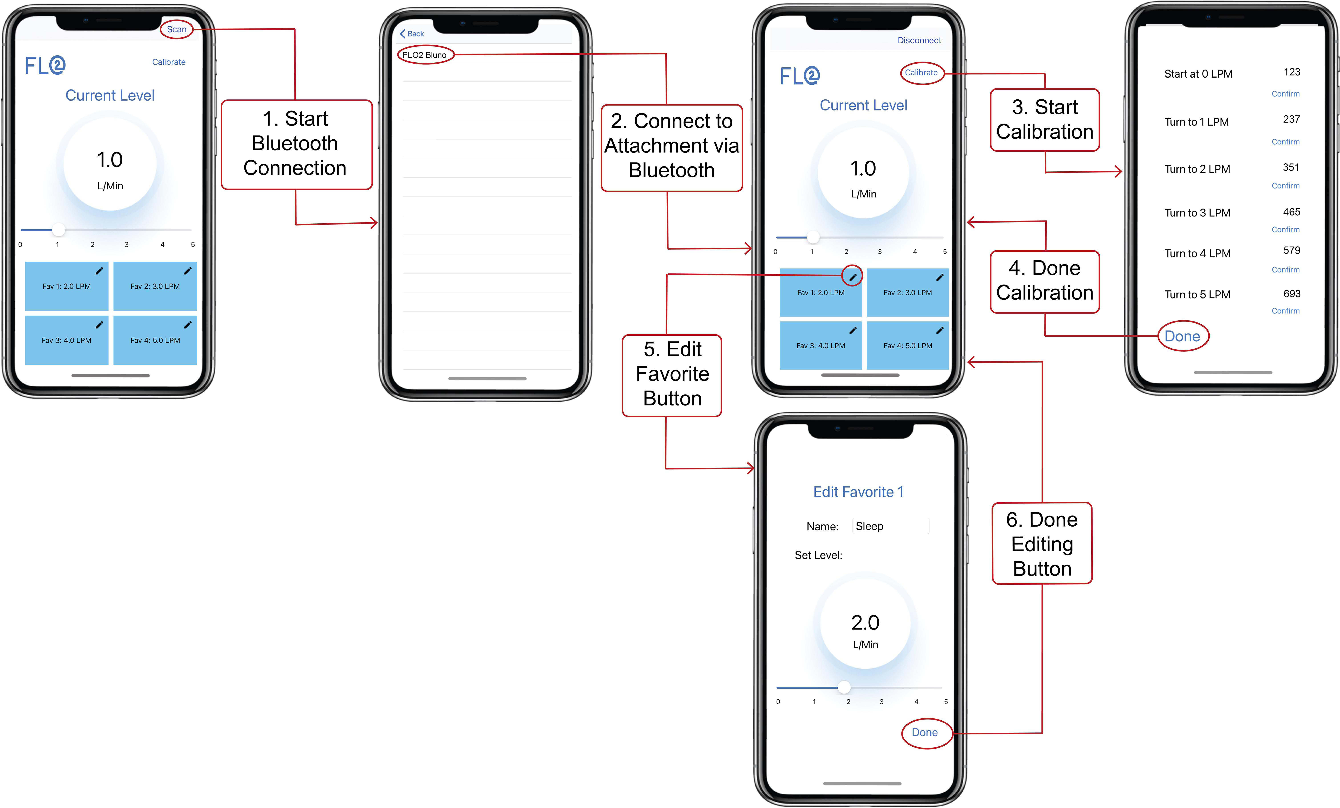
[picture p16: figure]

concentrator attachment before the Bluetooth disconnected in an open field. Through testing, it was found that the distance before disconnection was 41 meters in open space, which met the desired goal of ≥ 30 meters.
Reliability assessed two different facets of the system: 1) the app’s ability to connect via Bluetooth to the concentrator attachment in under 10 seconds and 2) the communication of actions performed on the app to the concentrator attachment. For these reliability standards to be met, at least 195 out of 200 (97.5%) trials performed had to be successful. In testing for reliability, there was successful Bluetooth pairing between the app and the attachment in under 10 seconds for 200 out of 200 (100%) trials. To test for the app adjustment reliability, a button press was

Table 2 Summary of Prototype Testing results

Design Criteria | Performance Criteria | Results
Bluetooth Range | Based on 3 trials, the average distance for the Bluetooth connection to disconnect is ≥ 30m | Success: Range of 41 m (~140 ft) in open space (n = 3)
Reliability | In 195 out of 200 trials, the time needed for successful Bluetooth
| pairing between the app and Bluno Beetle is < 10 seconds.

Success: 100% Bluetooth reliability (n = 200)

In 195 out of 200 trials, user action on the app (button press or slider adjustment) causes the attachment to adjust the flow rate.

Success: 100% App adjustment reliability (n = 200)

Flow Rate Accuracy | Based on 122 trials, the average absolute difference between the
| observed and target flow rate ≤ 0.25.

Success: Average flow difference from target flow = 0.019 LPM (n = 122)

Flow Rate Precision | Based on 122 trials, the average of the standard deviations of the
| observed flow rates for each target flow rate ≤ 0.25.

Success: Average standard deviation = 0.042 LPM (n = 122)

Abbreviations: CAD, computer aided design; PLA, polylactic acid; COPD, chronic obstructive pulmonary disease; AC/DC, alternating current/direct current; BLE, Bluetooth low energy.

Figure 6 iOS application wireframe displaying Bluetooth connectivity (Steps 1 and 2), calibration (Steps 3 and 4), and editing capability of the four favorite buttons (Steps 5 and 6).

Medical Devices: Evidence and Research 2023:16 | https://doi.org/10.2147/MDER.S407233 DovePress (https://www.dovepress.com)
97
Dovepress (https://www.dovepress.com) | Gadiraju et al

Powered by TCPDF (www.tcpdf.org) Powered by TCPDF (www.tcpdf.org)

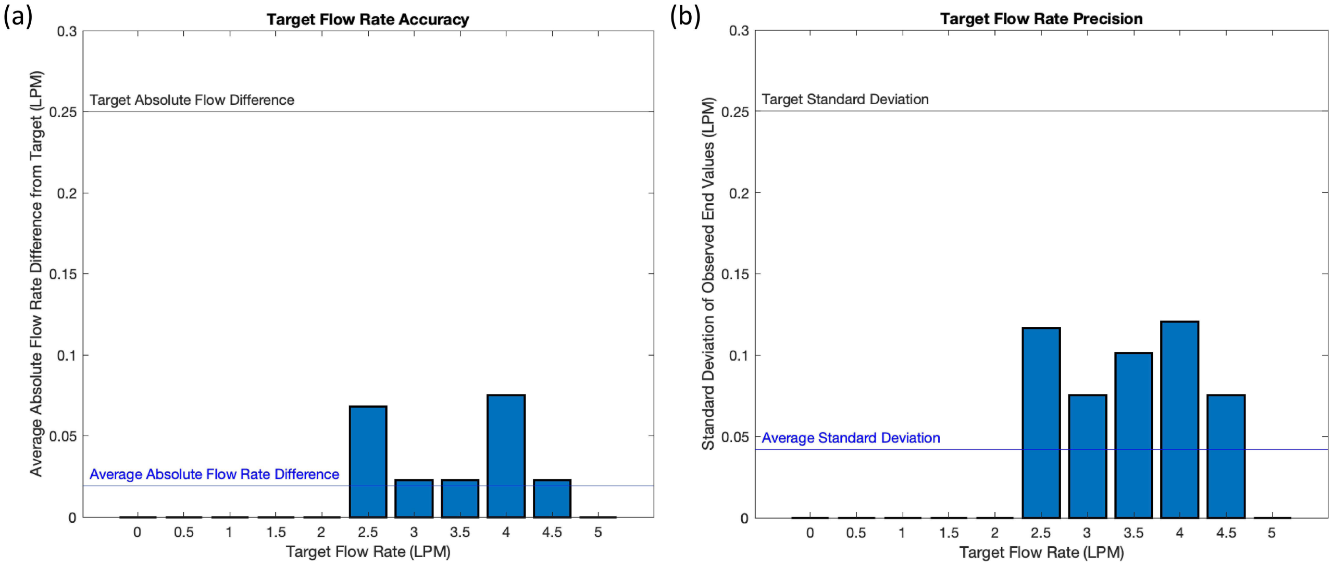
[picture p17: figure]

administered on the app, and if successful there would be an associated flow rate change. We found that 200 out of 200 (100%) trials were successful, which met the desired standard for app adjustment reliability.
To determine the accuracy and precision of the system, the performance of 122 flow rate adjustments, which included all possible start and end flow rate combinations, was analyzed. Accuracy was accessed by determining the absolute difference between the observed flow rate and the expected flow rate inputted by the user. The overall accuracy was ±0.019 LPM, and the average flow difference satisfied the target of 0.25 LPM for all target flow rates (Figure 7a). Precision was accessed by calculating the standard deviation of the observed flow rate for each expected flow rate inputted by the user. The overall precision was ±0.042 LPM, and the average standard deviation satisfied the target of 0.25 LPM across all target flow rates (Figure 7b). For both accuracy and precision, a maximum absolute difference or standard deviation of 0.25 LPM was acceptable because supplemental oxygen is prescribed in increments of 0.5 LPM. Therefore, any difference from the desired value of less than 0.25 LPM is highly unlikely to negatively affect the patient. Overall, the data demonstrated that the system can adjust the flow rate of the oxygen concentrator with a high level of accuracy and precision.

Discussion

With the increasing prevalence of chronic lung diseases and the COVID-19 pandemic, it is essential that home oxygen therapy patients have immediate control over their supplemental oxygen flow. To address this, the FLO2 oxygen concentrator control system was developed to reduce the risks of hypoxia and hyperoxia associated with movement for manual oxygen flow adjustment. For example, many patients turn the flow meter to 4–6 liter/min and leave it there all day due to the difficulty in changing it, which may risk toxic effects when the dose of oxygen is higher than the body’s demand. With our system, complications of hyperoxia can be avoided with the ability to turn flow rates down once the patient returns to a resting position. When paired with a pulse oximeter, our system also ensures with prescribed target SpO2 range (ex. a prescription of 90% to 92% SpO2). Increased accessibility may improve therapy compliance, increase patients’ quality of life, and lower the risks of adverse blood oxygen levels associated with home oxygen therapy. This two-part control system includes a mobile user application as well as a stationary attachment module to control for a 0–5 liter/min oxygen output flow rate.
Since home oxygen therapy is a medical treatment, the process of home oxygen therapy and any adjustments to the established practice must be accurate, precise, and closely monitored for reliability. Extensive testing of the FLO2 system concluded that the device successfully met the design criteria for precision, accuracy, and reliable

Figure 7 Flow rate accuracy (a) and precision (b) across all possible target flow rates (0–5 LPM). The performance criteria (0.25 LPM difference for both flow rate accuracy and precision) are represented by the black lines, while the average results are illustrated by the blue lines in both figures.

https://doi.org/10.2147/MDER.S407233
DovePress (https://www.dovepress.com)

### 98 Medical Devices: Evidence and Research 2023:16

Gadiraju et al | Dovepress (https://www.dovepress.com)

Powered by TCPDF (www.tcpdf.org) Powered by TCPDF (www.tcpdf.org)

performance. An accuracy of ±0.019 LPM proved that the device adjusts the oxygen concentrator to the desired flow rate, which is essential for patients who have exact calculated oxygen prescriptions from their physicians. Similarly, a standard deviation of ±0.042 LPM provides evidence of a high level of precision in receiving consistent flow rate values from the oxygen concentrator. Finally, there is reliable pairing of the smartphone app with the attachment module and consistent registration of any inputs by the user. Due to the combination of these experimental successes, patients may confidently rely on the device to provide the desired flow rate without a risk of a failed connection between the app and attachment module. Even in the case of an unforeseen malfunction, the device preserves the natural function of the oxygen concentrator, allowing patients to manually adjust the flow rate whenever necessary.
While the final prototype met all pre-determined design criteria, certain limitations in design and testing allow for future improvements. The maximum distance of Bluetooth connectivity was measured in open space instead of inside a residence, the likely setting for the device. Future testing should take into account various building materials, wall thickness, or size of the residence to accurately determine the Bluetooth range. Additionally, flow rate measurements were read from a floating ball flow meter attached to the concentrator, which is less precise than a digital readout found on more modern oxygen concentrators. To improve the accuracy of flow rate measurements, future trials should measure the actual output from the nozzle of the machine.
While our user needs assessment demonstrated a concern for the lack of remote adjustability and domiciliary accessibility, we had a small survey sample size of 12. To strengthen our user needs assessment, future work will conduct a more extensive survey with a larger, diverse sample of stationary oxygen concentrator users. Further testing of the device will involve evaluating its accuracy and reliability through feedback from oxygen therapy patients, with iterative improvements to be made based on their user experience. Future studies should investigate the compatibility of the FLO2 system with other stationary oxygen concentrator models and evaluate its clinical impact on patients with various respiratory conditions through randomized trials. The device can also be expanded to work with other oxygen therapy devices such as portable oxygen concentrators or compressed gas tanks. Moreover, we can integrate pulse oximetry with this oxygen control system to automate flow rate adjustment based on a patient’s blood-oxygen concentration. This system could also be adapted to control hospital oxygen, improving the accessibility of oxygen control for both patients and doctors in the future.

Conclusion

We developed and tested a novel oxygen control system to wirelessly control the flow rate of supplemental oxygen during home oxygen therapy. As an external add-on to existing oxygen concentrators, this system was demonstrated to be an accurate, precise, and reliable method for oxygen therapy patients to wirelessly adjust their oxygen flow rate within 41 meters. By eliminating the risks of hyperoxia and hypoxia associated with physical adjustment of oxygen concentrator flow meters, our system offers a safer and more accessible method for patients to control oxygen flow. Future work should focus on validating the accuracy and reliability of our device in a clinical study, exploring compatibility with other oxygen therapy devices, and integrating pulse oximetry to automate flow rate adjustment based on a patient’s blood-oxygen concentration. Further research and development of this device can lead to its integration with current oxygen therapy practices, ultimately improving oxygen flow control accessibility for both patients and healthcare providers.

Acknowledgments

We would like to thank Dr. Elizabeth Bucholz for her early guidance, Murad Maksumov for supplying tools and equipment, and Dr. Alejandro Piño for his clinical insights. This work was funded by the Duke University Pratt School of Engineering and the Duke Baquerizo Innovation Grant.

Disclosure

The authors report no conflicts of interest in this work.

Medical Devices: Evidence and Research 2023:16 | https://doi.org/10.2147/MDER.S407233 DovePress (https://www.dovepress.com)
99
Dovepress (https://www.dovepress.com) | Gadiraju et al

Powered by TCPDF (www.tcpdf.org) Powered by TCPDF (www.tcpdf.org)

References

1. Jacobs SS, Lederer DJ, Garvey CM, et al. Optimizing home oxygen therapy. An Official American Thoracic Society Workshop report. Ann Am Thorac Soc. 2018;15(12):13691381. doi:10.1513/AnnalsATS.201809-627WS (https://doi.org/10.1513/AnnalsATS.201809-627WS)
2. Sanchez-Morillo D, Olaby O, Fernandez-Granero MA, Leon-Jimenez A. Automatic recognition of daily physical activities for an intelligent-portable oxygen concentrator (ipoc). Adv Comput Intell. 2017;10305:212–221. doi:10.1007/978-3-319-59153-7_19 (https://doi.org/10.1007/978-3-319-59153-7_19)
3. Tanni SE, Vale SA, Lopes PS, Guiotoko MM, Godoy I, Godoy I. Influence of the oxygen delivery system on the quality of life of patients with chronic hypoxemia. J Bras Pneumol. 2007;33(2):161–167. doi:10.1590/s1806-37132007000200010 (https://doi.org/10.1590/s1806-37132007000200010)
4. Górecka D, Gorzelak K, Sliwiński P, Tobiasz M, Zieliński J. Effect of long-term oxygen therapy on survival in patients with chronic obstructive pulmonary disease with moderate hypoxaemia. Thorax. 1997;52(8):674–679. doi:10.1136/thx.52.8.674 (https://doi.org/10.1136/thx.52.8.674)
5. Stuart H. Long term domiciliary oxygen therapy in chronic hypoxic cor pulmonale complicating chronic bronchitis and emphysema. Report of the Medical Research Council Working Party. Lancet. 1981;1(8222):681–686.
6. Hardavella G, Karampinis I, Frille A, Sreter K, Rousalova I. Oxygen devices and delivery systems. Breathe. 2019;15(3):e108–e116. doi:10.1183/ 20734735.0204-2019 (https://doi.org/10.1183/20734735.0204-2019)
7. McDonald CF. Oxygen therapy for COPD. J Thorac Dis. 2014;6(11):1632–1639. doi:10.3978/j.issn.2072-1439.2014.10.23 (https://doi.org/10.3978/j.issn.2072-1439.2014.10.23)
8. Chai SW, Kothare MV, Sircar S. Rapid pressure swing adsorption for reduction of bed size factor of a medical oxygen concentrator. Ind Eng Chem Res. 2011;50(14):8703–8710. doi:10.1021/ie2005093 (https://doi.org/10.1021/ie2005093)
9. Claure N, Bancalari E. Automated closed loop control of inspired oxygen concentration. Respir Care. 2013;58(1):151–161. doi:10.4187/respcare.01955 (https://doi.org/10.4187/respcare.01955)
10. Casanova C, Hernández MC, Sánchez A, et al. Twenty-four-hour ambulatory oximetry monitoring in COPD patients with moderate hypoxemia. Respir Care. 2006;51(12):1416–1423.
11. Sanchez-Morillo D, Olaby O, Fernandez-Granero MA, Leon-Jimenez A. Physiological closed-loop control in intelligent oxygen therapy: a review. Comput Methods Programs Biomed. 2017;146:101–108. doi:10.1016/j.cmpb.2017.05.013 (https://doi.org/10.1016/j.cmpb.2017.05.013)
12. Shinoda M, Shinkai M, Nagashima A, Nagai K, Takagi K, Kaneko T. Modification of oxygen concentrators based on questionnaire survey. Clin Respir J. 2018;12(5):1937–1941. doi:10.1111/crj.12761 (https://doi.org/10.1111/crj.12761)
13. Sanchez-Morillo D, Muñoz-Zara P, Lara-Doña A, Leon-Jimenez A. Automated home oxygen delivery for patients with COPD and respiratory failure: a new approach. Sensors. 2020;20(4):1178. doi:10.3390/s20041178 (https://doi.org/10.3390/s20041178)
14. Dym CL, Little P, Dym CL, Dym CL. Engineering Design: A Project-Based Introduction. New York: Wiley; 2000.
Medical Devices: Evidence and Research | Dovepress (https://www.dovepress.com)

Publish your work in this journal

Medical Devices: Evidence and Research is an international, peer-reviewed, open access journal that focuses on the evidence, technology, research, and expert opinion supporting the use and application of medical devices in the diagnosis, monitoring, treatment and management of clinical conditions and physiological processes. The identification of novel devices and optimal use of existing devices which will lead to improved clinical outcomes and more effective patient management and safety is a key feature of the journal. The manuscript management system is completely online and includes a very quick and fair peer-review system. Visit http://www.dovepress.com/testimonials.php to read real quotes from published authors.

Submit your manuscript here: https://www.dovepress.com/medical-devices-evidence-and-research-journal

DovePress (https://www.dovepress.com) | Medical Devices: Evidence and Research 2023:16 100
Gadiraju et al | Dovepress (https://www.dovepress.com)

Powered by TCPDF (www.tcpdf.org) Powered by TCPDF (www.tcpdf.org)

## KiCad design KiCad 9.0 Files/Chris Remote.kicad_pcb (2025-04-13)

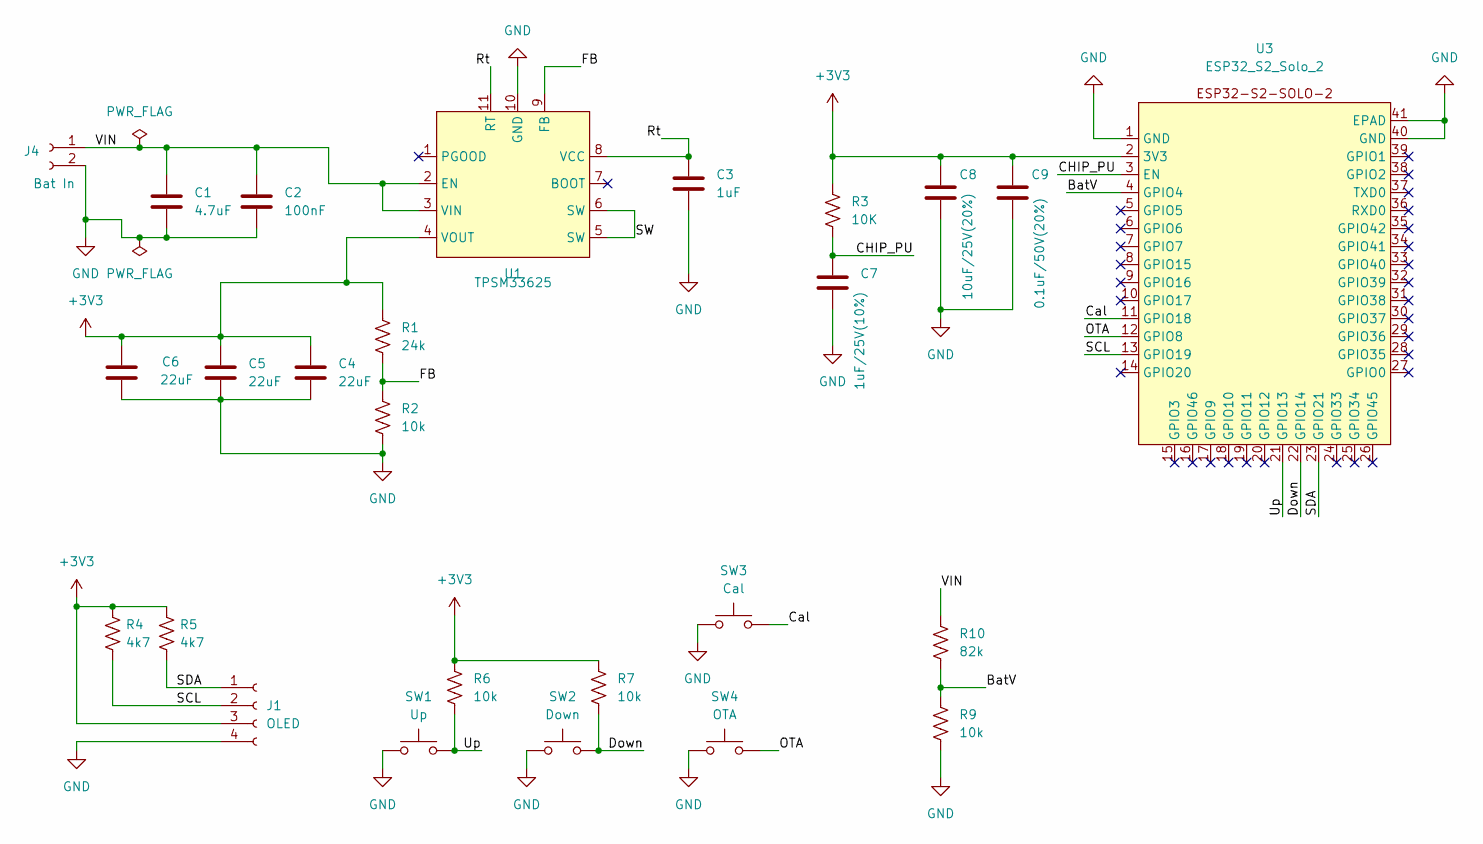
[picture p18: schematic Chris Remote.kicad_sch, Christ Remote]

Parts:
C1: 4.7uF; C_1206_3216Metric; LCSC Part Number C29823
C2: 100nF; C_0402_1005Metric; LCSC Part Number C307331
C3: 1uF; C_1206_3216Metric; LCSC Part Number C1848
C4, C5, C6: 22uF; C_0805_2012Metric; LCSC Part Number C45783
C7: 1uF/25V(10%); C_0402_1005Metric; LCSC Part Number C52923
C8: 10uF/25V(20%); C_0603_1608Metric; LCSC Part Number C96446
C9: 0.1uF/50V(20%); C_0603_1608Metric; LCSC Part Number C14663
J1: OLED; PinHeader_1x04_P2.54mm_Vertical
J4: Bat In; JST_XH_B2B-XH-A_1x02_P2.50mm_Vertical
R1: 24k; R_0603_1608Metric; LCSC Part Number C23352
R2, R6, R7, R9: 10k; R_0603_1608Metric; LCSC Part Number C25804
R3: 10K; R_0402_1005Metric; LCSC Part Number C25744
R4, R5: 4k7; R_0603_1608Metric; LCSC Part Number C23162
R10: 82k; R_0603_1608Metric; LCSC Part Number C23254
SW1: Up; SW_PUSH_6mm_H5mm
SW2: Down; SW_PUSH_6mm_H5mm
SW3: Cal; SW_PUSH_6mm_H5mm
SW4: OTA; SW_PUSH_6mm_H5mm
U1: TPSM33625; QFN-FCMOD; LCSC Part Number C7073593
U3: ESP32_S2_Solo_2; ESP32_S2_SOLO_2

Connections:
+3V3: C4.1, C5.1, C6.1, C8.1, C9.1, J1.3, R1.1, R3.1, R4.1, R5.1, R6.1, R7.1, U1.4 (VOUT), U3.2 (3V3)
/BatV: R9.1, R10.2, U3.4 (GPIO4)
/CHIP_PU: C7.1, R3.2, U3.3 (EN)
/Cal: SW3.2, U3.11 (GPIO18)
/Down: R7.2, SW2.2, U3.22 (GPIO14)
/FB: R1.2, R2.1, U1.9 (FB)
/OTA: SW4.2, U3.12 (GPIO8)
/Rt: C3.1, U1.8 (VCC), U1.11 (RT)
/SCL: J1.2, R4.2, U3.13 (GPIO19)
/SDA: J1.1, R5.2, U3.23 (GPIO21)
/SW: U1.5 (SW), U1.6 (SW)
/Up: R6.2, SW1.2, U3.21 (GPIO13)
/VIN: C1.1, C2.1, J4.1, R10.1, U1.2 (EN), U1.3 (VIN)
GND: C1.2, C2.2, C3.2, C4.2, C5.2, C6.2, C7.2, C8.2, C9.2, J1.4, J4.2, R2.2, R9.2, SW1.1, SW2.1, SW3.1, SW4.1, U1.10 (GND), U3.1 (GND), U3.40 (GND), U3.41 (EPAD)

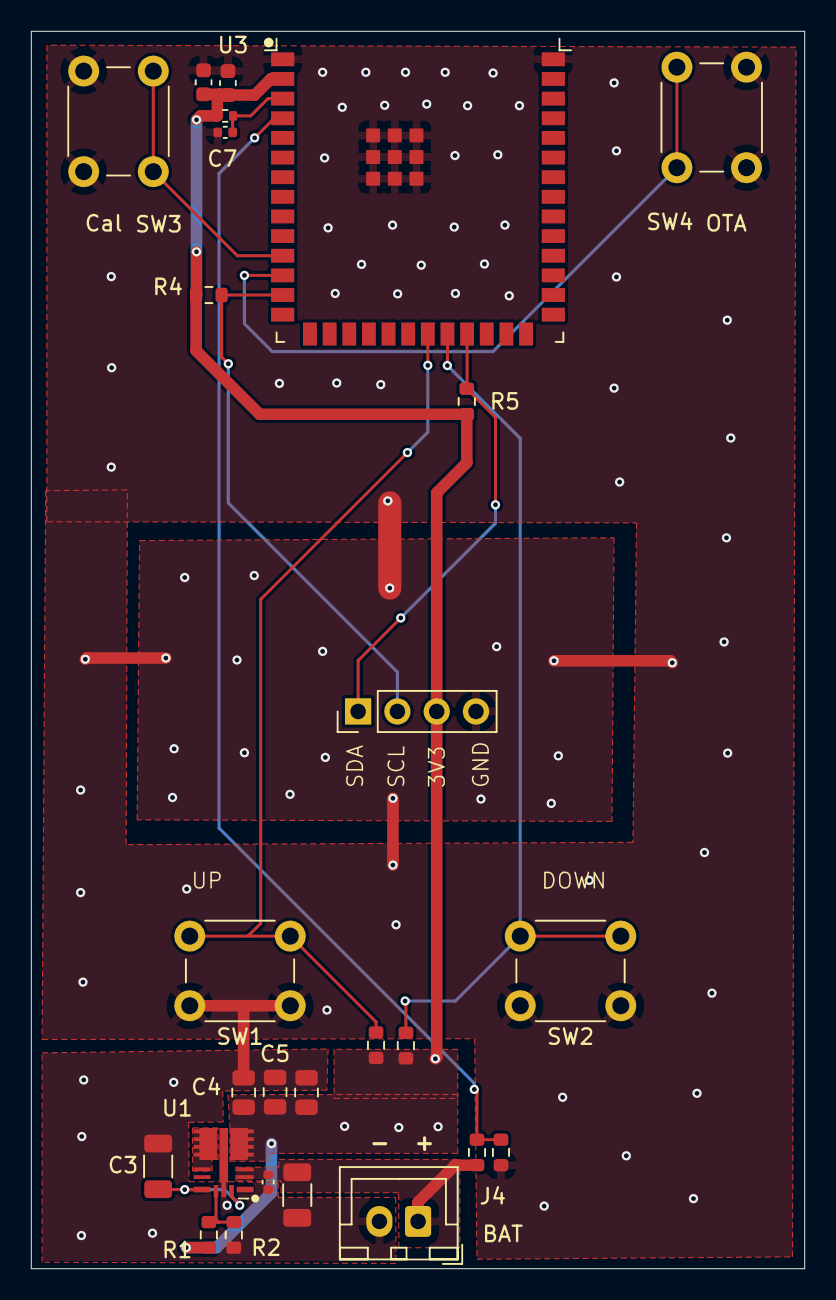
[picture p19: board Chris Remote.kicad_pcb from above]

Board: 2 copper layers, 50.0 x 80.0 mm, 26 parts (0 on the bottom side), 14 nets.

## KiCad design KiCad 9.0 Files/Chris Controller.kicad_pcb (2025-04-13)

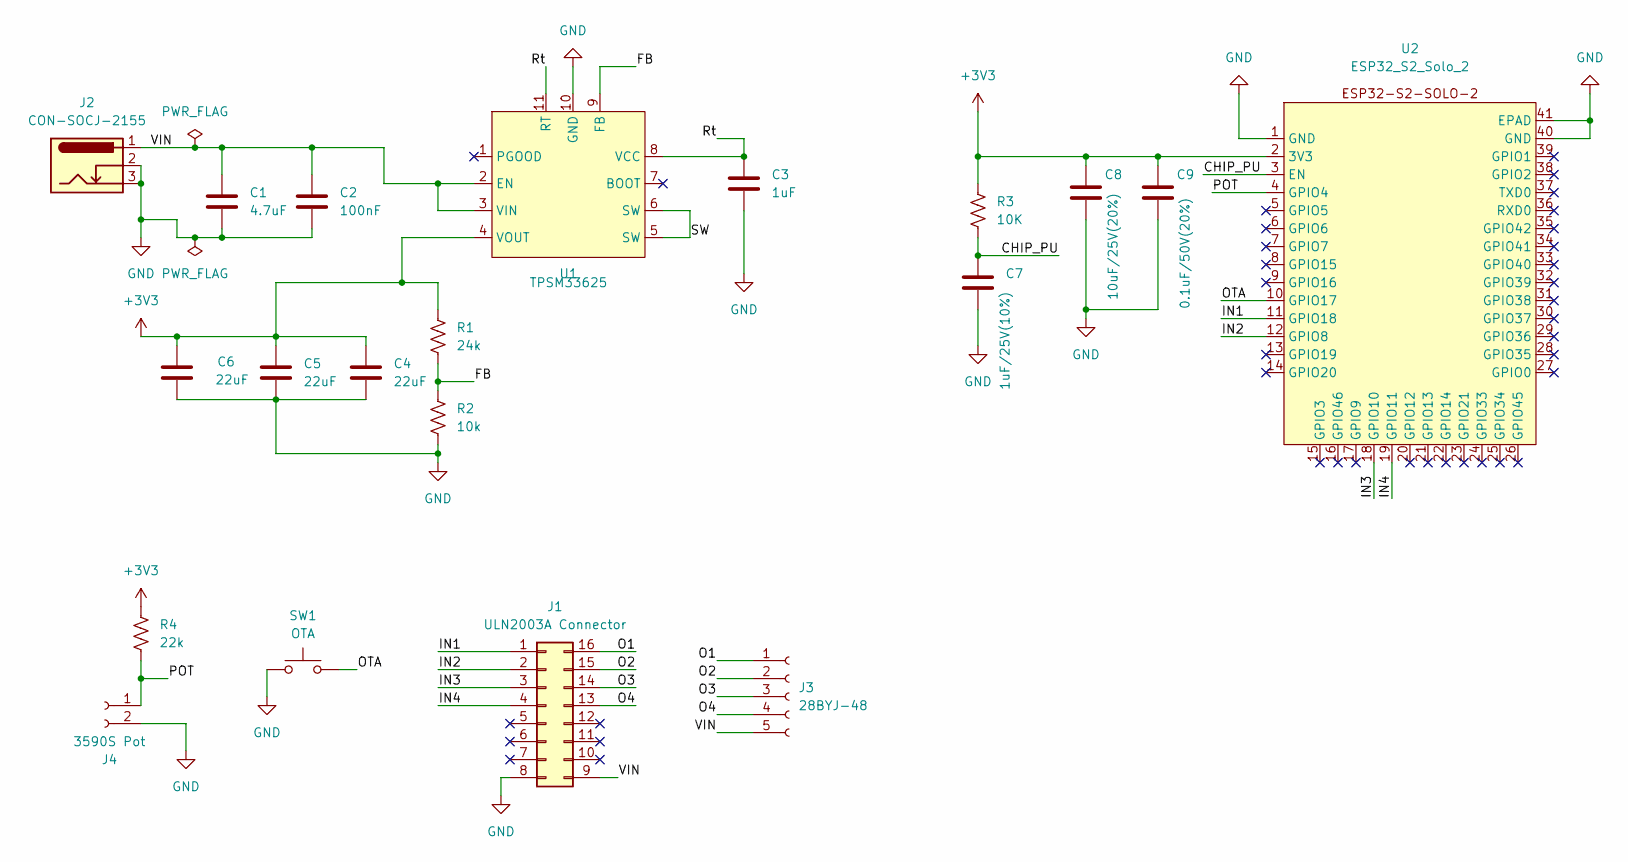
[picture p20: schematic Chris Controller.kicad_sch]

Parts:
C1: 4.7uF; C_1206_3216Metric; LCSC Part Number C29823
C2: 100nF; C_0402_1005Metric; LCSC Part Number C307331
C3: 1uF; C_1206_3216Metric; LCSC Part Number C1848
C4, C5, C6: 22uF; C_0805_2012Metric; LCSC Part Number C45783
C7: 1uF/25V(10%); C_0402_1005Metric; LCSC Part Number C52923
C8: 10uF/25V(20%); C_0603_1608Metric; LCSC Part Number C96446
C9: 0.1uF/50V(20%); C_0603_1608Metric; LCSC Part Number C14663
J1: ULN2003A Connector; DIP-16_W7.62mm_Socket
J2: CON-SOCJ-2155; GRAVITECH_CON-SOCJ-2155
J3: 28BYJ-48; JST_XH_B5B-XH-A_1x05_P2.50mm_Vertical
J4: 3590S Pot; JST_XH_B2B-XH-A_1x02_P2.50mm_Vertical
R1: 24k; R_0603_1608Metric; LCSC Part Number C23352
R2: 10k; R_0603_1608Metric; LCSC Part Number C25804
R3: 10K; R_0402_1005Metric; LCSC Part Number C25744
R4: 22k; R_0603_1608Metric; LCSC Part Number C31850
SW1: OTA; SW_PUSH_6mm_H5mm
U1: TPSM33625; QFN-FCMOD; LCSC Part Number C7073593
U2: ESP32_S2_Solo_2; ESP32_S2_SOLO_2

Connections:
+3V3: C4.1, C5.1, C6.1, C8.1, C9.1, R1.1, R3.1, R4.1, U1.4 (VOUT), U2.2 (3V3)
/CHIP_PU: C7.1, R3.2, U2.3 (EN)
/FB: R1.2, R2.1, U1.9 (FB)
/IN1: J1.1, U2.11 (GPIO18)
/IN2: J1.2, U2.12 (GPIO8)
/IN3: J1.3, U2.18 (GPIO10)
/IN4: J1.4, U2.19 (GPIO11)
/O1: J1.16, J3.1
/O2: J1.15, J3.2
/O3: J1.14, J3.3
/O4: J1.13, J3.4
/OTA: SW1.2, U2.10 (GPIO17)
/POT: J4.1, R4.2, U2.4 (GPIO4)
/Rt: C3.1, U1.8 (VCC), U1.11 (RT)
/SW: U1.5 (SW), U1.6 (SW)
/VIN: C1.1, C2.1, J1.9, J2.1, J3.5, U1.2 (EN), U1.3 (VIN)
GND: C1.2, C2.2, C3.2, C4.2, C5.2, C6.2, C7.2, C8.2, C9.2, J1.8, J2.2, J2.3, J4.2, R2.2, SW1.1, U1.10 (GND), U2.1 (GND), U2.40 (GND), U2.41 (EPAD)

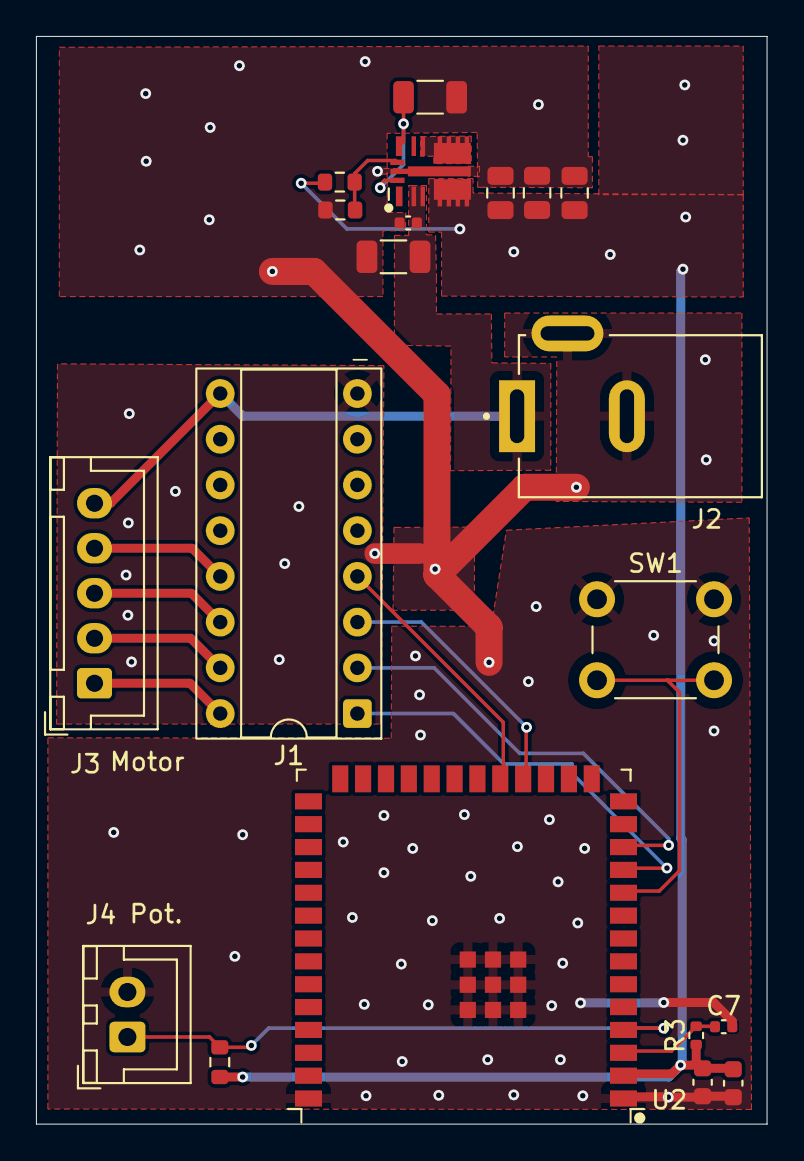
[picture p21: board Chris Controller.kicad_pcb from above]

Board: 2 copper layers, 40.6 x 60.4 mm, 20 parts (0 on the bottom side), 17 nets.

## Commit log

2025-03-28 Create Readme.md
    KiCad 9.0 files giving schematics, PCB layout, LSCS Part numbers which are necessary to have JLCPCB.com manufacture the PCB's
2025-04-15 Update Readme
    Redirect to ESP32_Chris_Controller repository for code
2025-04-15 Update Readme
    Redirect to ESP32_Chris_Remote repository for code
